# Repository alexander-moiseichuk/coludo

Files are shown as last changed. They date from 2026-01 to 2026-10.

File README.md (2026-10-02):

# coludo

This repository is to represent and control the rocket powered glider.
Since I do not know C/C++, it will be less complex than [HPR Rocket Flight Computer](https://github.com/SparkyVT/HPR-Rocket-Flight-Computer) this project will be written with MicroPython.
The composion of [hardware components](doc/hardware.md) is in progress with weight/power consumption restrictions in the account.

**Board revisions.** One firmware runs three of them and decides which it is on at boot, by I²C scan
([`layout.py`](src/glider/layout.py)) — no config edit when a board is rewired:

| rev | attitude module | also |
| --- | --- | --- |
| **v0.1** | sen0253 (BNO055 `0x28` + BMP280 `0x76`) | ADXL375 ±200 g on SPI |
| **v1.0** | sen0253 | ADXL375 removed; the ICP-10111, pitot and laser move to their own 100 kHz bus |
| **v1.1** | **sen0697** (BMI323 `0x69` + BMP581 `0x47` + **BMM350 `0x15`**) | first board with a magnetometer; the board fuses attitude itself |

The v1.1 change is measured in [TMS-7-board_v1.1_sen0697](doc/sims/TMS-7-board_v1.1_sen0697/):
across 60 board flights the two revisions fly the **same aircraft** — landing accuracy, fin activity
and in-flight health are all within run-to-run noise. What separates them is redundancy, not
performance: v1.1 gains a magnetometer and a second gyro source and gives up its second attitude
source. The magnetometer's value looked clear over 12 paired flights and did not survive 24.

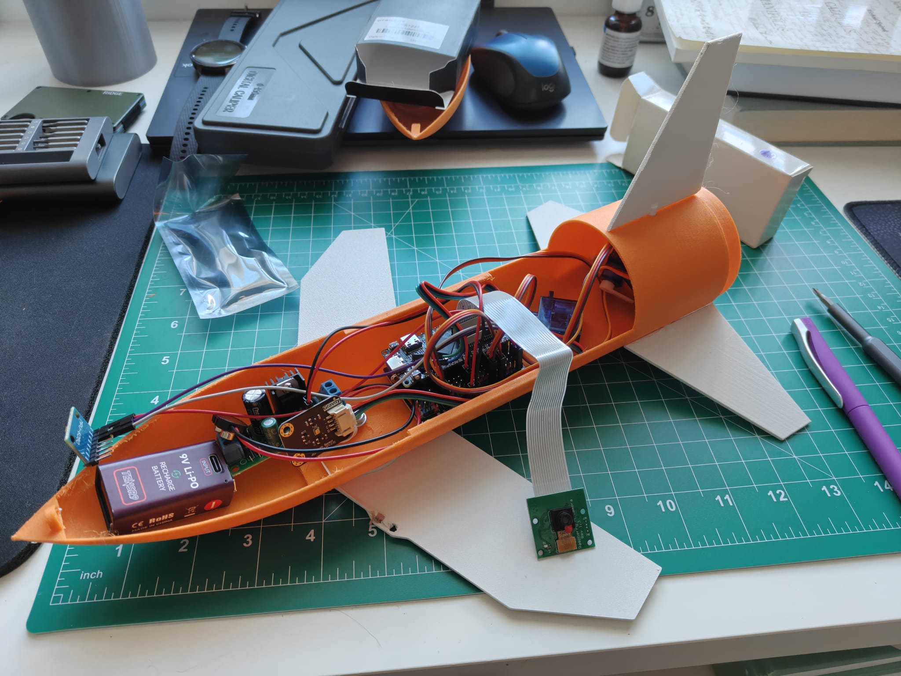
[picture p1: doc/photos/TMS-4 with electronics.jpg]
found in here
The old glider version TMS-4 can be 

The glider version TMS-7 avaliable there

## Where things live

**Specifications — [`doc/specs/`](doc/specs/)**
- [Architecture overview](doc/specs/coludo.md) — the **main description**: flight lifecycle (Setting → Boosting → Gliding → Landing), flight controller, sensors, telemetry and logging. Authoritative for flight behaviour.
- [Board configuration](doc/specs/board-config.md) — the controller's config schema, the three config layers, and the save/reboot activation lifecycle.
- [Control Center ↔ board protocol](doc/specs/cc-protocol.md) — the wire protocol between the ground station and the boards, plus the browser bridge.

**Documentation — [`doc/`](doc/)**
- [Hardware](doc/hardware.md) — parts list, weights, power budget, and candidate build configurations.
- [Data sources](doc/datasources.md) — every measured quantity with its primary source, backups and rates, per board revision, and which channels lose redundancy where.
- [WaveShare ESP32-P4-WIFI6 pin map](doc/waveshare_esp32p4_pins.md) — reserved vs free GPIOs and the recommended `board.config` pin assignment.
- [Tasks & plans](doc/plan.md) — required hardware checklist and the phased development roadmap.
- [Development & testing guide](doc/skills.md) — tooling (`ampy`/`mpremote`/`rshell`, `mpy-cross`), source layout, the `panda` test network, and the testing rules.
- [Flight simulations](doc/sims/) — closed-loop host + on-board HITL flights (noise/wind/corner sweeps) with interactive reports.
- [Benchmarks](doc/benches/) — board performance logs (BeagleBone, RPi4, StarFive).
- [Photos](doc/photos/) — build and electronics photos.
- [Videos](doc/videos/) — flight footage (e.g. the TMS-6 campaign).

**Models — [`models/`](models/)** — 3D-printable STL parts for the booster and glider prototypes (TMS-1 … TMS-7).

**Source — [`src/`](src/)**
- [`src/glider/`](src/glider/) — Main Controller flight firmware (MicroPython), with tests in `src/glider/test/`. *(implemented)*
- [`src/control/`](src/control/) — Control Center ground station (Python) + browser dashboard. *(implemented)*
- [`src/camera/`](src/camera/) — Recorder module (Luckfox Pico): 2304×1296 video + UART telemetry/log sink. *(implemented)*
- [`src/logger/`](src/logger/) — standalone nose logger (ESP32-C6 + SEN0697 + 120 mAh LiPo): a self-contained
  payload that records boost acceleration and apogee altitude for a flight the main controller is not on. *(implemented)*

**Tools — [`tools/`](tools/)** — various tools which helps in development and setup.

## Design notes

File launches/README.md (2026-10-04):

# Launches

One folder per launch day, `YYYYMMDD`, holding the flight manifest and **the board configs as they
flew**.

Configs live here rather than in a shared `configs/` because a profile is only meaningful beside the
airframe it was written for: the masses, the motor, the fin setting and the electronics fitted all
change from launch to launch, and a config that outlives them is a config nobody can trust. Regenerate
into a launch with `python3 tools/make_telemetry_config.py --launch <YYYYMMDD>` (default: the newest).
It writes the v0.1 profiles only (7C, 7D, 7D control) — keyless `layout` (declared v0.1) and the
VL53L4CX as their one enabled laser; 7E/7F are hand-kept. **Every board enables exactly one laser
entry**: an unfitted one fails `verify` and `arm`.

| launch | status |
|---|---|
| [20261003](20261003/README.md) | **flown** — [TMS-7](20261003/TMS-7/README.md) booster test: success, full flight logged; TMS-7F not assembled in time |
| ~~20260905~~ | **cancelled — weather** |

Motor masses used throughout, both measured (`doc/hardware.md`): **F15-4 98.8 g**, **E16 ~82.5 g**
loaded. Airframe masses in each manifest are **without** the motor; the totals add it.

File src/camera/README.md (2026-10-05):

# camera recoding support

It seems Luckfox Pico Mini and sc3336 can support out of box decent 2304x1296 30 FPS experience for small weight:
- board + 64 GB card
- camera
- power boost
- battery (3.7 1 cell LiPo) + 5V booster
- all together weight 30 gramms

The 32GB card or less will be sufficient but on launch pad missie may stay 15 minutes or more, so avoid losing
launch experience it must recorded in format which allows to survice for all possible frames. In top resolution
only mpeg works fine as VI channel has enought memory. The load about 30% and temperature hits acceptable 55-60C
without any passive cooling. Videos writing into /userdata/videos (see opt/camera/camerad.conf), so this area nice
to have 10+ GB as 15 mins default video consumes ~3.5GB

See sc3336.txt for possible formats but for fast implementation the existing framework is used from /oem/usr/bin:
- rkaiq_3A_server supports proper channel setup (not green, not dark)
- simple_vi_bind_venc is a nice tool to write in mjpeg (save until last frame) for ~15 mins clips (~3.5GB) with 30 FPS

You can choose (see opt/camera/camerad.conf) h264 or h265 but you have to reduce resoltution or increase CMA size in kernel
over default 24MB. Now for 64MB board 15 MB stil available and not much space to play around, so mjpeg is simply fits out of box.

# installation

push files to device, e.g.

	$ adb push opt/* /opt/

link in startup scripts e.g. 
```
	# adb shell
	# ln -s /opt/camera/camerad.sh /etc/init.d/S99camerad
	# ln -s /opt/hwclock/hwclockd.sh /etc/init.d/S20hwclockd      <--- this one optional
	# chmod -x $(which rkipc)                                     <--- it consumes a lot of cycles unnecessary
        # update date to current if you need
        # sync
        # poweroff
```

if started from USB-power supply (not PC+rndis) it will start writing files /userdata/videos/000-2304x1296.mjpeg etc.
to indicate it during boot LED does ~5s ON period and then start actively blinking following mmc1 activity,
otherwise turned off.

in case of PC script should not start allowing download videos in easy way and LED is OFF.

# recorded

The SPI + GIL seems potentially can do 80-100 ms freeze of Micropython, so to solve issue with storing telemetry and logs the recorded is required.
It works fine for 921600 bod using single wire to deliver information throgh UART to Luckfox board which needs to be configured using luckfox-config
to enable /dev/ttyS3 or /dev/ttyS4. Installation is easy - just required RX pin to be connected from TX pin of microcontoller and enabled duing boot
```
	# adb shell
	# ln -s /opt/recorded/recorded.sh /etc/init.d/S99recorded
        # sync
        # poweroff
```
Expected format is simple:
	contents line\n
or
	@target_file@contents line\n

In first case all unknown lines will be added into predefined in config file (`/userdata/recordings/recorder.log`), in second case line will be added into
`/userdata/recordings/target_file`. So, practically any logging and CSV telemetry can be stored this way.

The daemon stays exactly this simple. The board wraps every payload in an integrity check,
`{crc32};<payload>;<~crc32 ^ uptime>`, which the daemon stores verbatim and the host tools verify. It
names each boot's files by an NVS boot id, `000123_<stream>.csv`, and lists every boot and each clock
set in a shared `session.csv`. See [`doc/specs/recorder-wire.md`](../../doc/specs/recorder-wire.md).

Run the camera **off** while recording telemetry. In a closed airframe the module overheats within
~10 min (the video distorts), and video plus logging is more than it handles. `/userdata` is remounted
`commit=1` by `opt/recorder/recorderd.sh`.

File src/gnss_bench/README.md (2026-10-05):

# GNSS bench checker

[`main.py`](main.py) checks two GNSS modules in the field. They get **our flight init** plus slow diagnostics,
and the checker records what they do. It runs on an **ESP32-C6 SuperMini** with **MicroPython ≥ 1.29**. It is
not flight firmware: `tools/deploy.sh` never touches it. The first result is
[doc/benches/gnss-20261004](../../doc/benches/gnss-20261004/README.md).

## Wiring

| module | module TX → C6 | module RX ← C6 | UART | baud |
|---|---|---|---|---|
| ATGM336H | GPIO4 | GPIO5 | `UART(2)`, the C6's LP UART (fixed pins) | 9600 |
| NEO-6M | GPIO7 | GPIO6 | `UART(1)` | 9600 |

Power the C6 and both modules together. A module that powers up with the C6 gets up to 5 s to start talking
before it is configured anyway.

* **LED:** the SuperMini's RGB LED (WS2812, GPIO8). Solid **green** while it works; solid **red** once a save
  failed.
* **No button.** The SuperMini's BOOT button never registered on GPIO9 on this unit, so the checker needs
  none.

## A session per power-on

Every power-on starts session N, numbered on from the highest `336.N` on flash. Each module gets the flight
init once it talks, as `drivers/atgm336h.py` (hz 10) and `drivers/neo6mv2.py` (hz 5) send it. Then come the
diagnostics: GSV, GSA and the ATGM's antenna text every ~10 s, which leave the RMC/GGA rates as they are.
After that:

* every 10 s, a `status` line per module: RMC valid, GSA mode, GGA quality, satellites used and HDOP,
  satellites in view, the best four C/N0, the antenna text, UTC and the position;
* at a module's first 3D fix, a `fix3d` record with the last 100 NMEA lines;
* every 30 s, the moment files are rewritten with each module's last 100 lines, both at one instant, so
  pulling the battery loses at most the last 30 s.

## Files

| file | what |
|---|---|
| `336.N` / `neo6.N` | the ATGM / NEO in session N: `start`, `talking` (or `silent`), the `tx` commands sent, the first 10 NMEA lines, the `status` lines, the `fix3d` record |
| `336.N.x` / `neo6.N.x` | the last moment: `moment`, the situation, the last 100 lines |

A saved NMEA line is `<uptime ms>;<line verbatim>`. [`main.py`](main.py)'s header has the full record format.
The fixed status lines, the `fix3d` records and the moment files hold **the position at metre precision**.

## Install, read out, report

Connect the C6 **directly to the PC, never through a USB hub**: the hub corrupts mpremote transfers.

```
mpremote connect /dev/ttyACM0 cp src/gnss_bench/main.py :main.py          # install
mpremote connect /dev/ttyACM0 ls                                           # which sessions are there
mpremote connect /dev/ttyACM0 cp :336.5 :336.5.x :neo6.5 :neo6.5.x <dir>/  # read out (every N)
```

The read-out power-on starts a session too: the newest one, with almost no status lines. mpremote's Ctrl-C
ends it. To start numbering from 1 again, remove the old session files.

```
python3 tools/gnss_bench_report.py <dir> --label 1=none 5=small ... [-o summary.csv]
```

The report gives one row per session and module: the run, the 3D-fix time, when the RMC turned valid
(between two readings: the status lines and the `fix3d` record's situation), valid status lines, satellites
in view and used, the best C/N0 and the best top-4 mean, the antenna text, and the CEP50 and farthest fix
about the median. It never prints the position. Then it compares the two modules on the same satellites,
from one read-out of their moment files.

The session files hold the bench site's position: keep them local, out of git. To pin them in a write-up
without publishing them, print a keyed digest per file:

```
python3 tools/gnss_bench_report.py --provenance <dir>
```

Each line is `<file>;<HMAC-SHA256>`, keyed with `<dir>/.pepper`: 32 random bytes made on first use,
owner-only, never printed, and git-ignored by name. A plain hash would let anyone confirm a guessed position.

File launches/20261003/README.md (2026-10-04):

# Launch 2026-10-03 — HPRC

Rescheduled from **2026-09-05, cancelled for weather**.

Seven slots: one booster-only structural test, two glide-comparison airframes, one telemetry airframe,
one servo-equipped airframe, and two airframes on the new main boards: TMS-7E (v1.0) and TMS-7F
(v1.1), both built.

## Manifest

Airframe masses are **as assembled, without the motor**. Motor masses are the measured values from
`doc/hardware.md` — **F15-4 98.8 g**, **E16 ~82.5 g** loaded.

| airframe | glider | booster | motor | + motor | **liftoff** | glide mass |
|---|---|---|---|---|---|---|
| [TMS-7](TMS-7/README.md) | — | **129.5 g** | F15 | 98.8 g | **228.3 g** | n/a (no glider) |
| [TMS-7A](TMS-7A/README.md) | 183.0 g | 99.0 g | E16 | 82.5 g | **364.5 g** | 183.0 g |
| [TMS-7B](TMS-7B/README.md) | 184.3 g | 98.2 g | E16 | 82.5 g | **365.0 g** | 184.3 g |
| [TMS-7C](TMS-7C/README.md) | 216.5 g | 98.9 g | F15 | 98.8 g | **414.2 g** | 216.5 g |
| [TMS-7D](TMS-7D/README.md) | 287.5 g | 97.9 g | F15 | 98.8 g | **484.2 g** | 287.5 g |
| [TMS-7E](TMS-7E/README.md) | 250.0 g | 94.8 g | F15 | 98.8 g | **443.6 g** | 250.0 g |
| [TMS-7F](TMS-7F/README.md) | *not assembled in time — not flying 10-03* | — | — | — | — | — |

## What each slot answers

* **TMS-7** — does the new booster construction survive the strongest motor? Structure only, no glider,
  but carrying the 10 g nose logger so it also returns peak boost acceleration and apogee altitude.
  The F15 is deliberate: test the worst case before trusting it under an instrumented airframe.
  **Result: yes.** It flew to ~470 m (14.9 g peak, 125 m/s) and came back intact, and the logger returned
  the whole flight. These are the boundaries for every F15 airframe; see [TMS-7](TMS-7/README.md).
* **TMS-7A vs TMS-7B** — the wing comparison, flown as a matched pair on the same motor: **ASE wings
  with fins at 0°** against **carbon wings with fins at −5°**. Dual cameras, 1.3 g apart in mass, so the
  difference that shows up is the wing and the fin setting rather than the build.
* **TMS-7C** — telemetry. Fins **fixed at whatever 7A/7B selects**, so the instrumented flight uses the
  setting the comparison just validated rather than a guess.
  **Result: crashed.** Fins at 0°. The stack lost boost stability just off the rod (roll torque ∝ q,
  up to 9.3 g sideways), looped under thrust and hit the ground; the recorder kept 1.31 s. Hardware to
  be validated for December; see [TMS-7C](TMS-7C/README.md).
* **TMS-7D** — the servo airframe: three SG90s and the full power module.
  **Result: no separation, dropped.** It bent over in a ~4.5 m/s crosswind to a 32° path but stayed
  bounded. Apogee was 91–98 m at 5.4 s; the glider never separated, and the stack came down ~250 m out.
  The recorder kept 6.4 s. See [TMS-7D](TMS-7D/README.md).
* **TMS-7E** — the first airframe on main board v1.0, where the payoff is mass; see its folder.
  **Result: no separation, dropped.** The PCB broke in two, and the recorder's SD card is electrically dead
  (it heats to 60 °C+, never initialises), so there is no data.
* **TMS-7F** — the first v1.1 airframe (SEN0697: the board fuses its own attitude and carries a
  magnetometer); see its folder.

## What 10-03 measured — summary

Recorded flights: **TMS-7** (nose logger, the whole flight), **TMS-7C** (recorder, the first 1.31 s),
**TMS-7D** (recorder, the first 6.42 s). 7E's card died; 7F did not fly. Each flight was cut from its
recorder dump by `src/logger/flight.py` or `tools/recorder_flight.py` and measured with a gyro-plus-
accelerometer strapdown. Each was then checked by independent analyses and an adversarial judge,
recomputing from the data; the details are in each airframe's README. Not much data in total, but
enough to bound the dynamics and to show which sensors work in flight.

### What happened

| | outcome | why, as far as the data says |
|---|---|---|
| TMS-7 | **success**: 464–479 m, chute recovery | motor normal; the chute partly collapsed below ~150 m (descent 6.5 → 11 m/s) |
| TMS-7C | **looped and crashed** within ~2.5 s | a boost-stability departure at rod exit (0.31 s): near-neutral margin plus a built-in roll asymmetry; 9.3 g aerodynamic side load |
| TMS-7D | **no separation, dropped** ~250 m out | bent over in a crosswind but stayed bounded; low apogee (91–98 m); separation never happened before 6.42 s |
| TMS-7E | **no separation, dropped**; PCB broken | no data (SD card dead) |

### The corner parameters

The extremes these flights reached, against each sensor's range:

| quantity | measured | sensor range / note |
|---|---|---|
| boost peak (axial) | **14.9 g** (TMS-7, 228 g) · 8.25 g (7C, 414 g) · 6.2–6.7 g (7D, 484 g) | BMI323 ±16 g: **93 %**; peak g ≈ 32 N ÷ mass |
| shocks | 19 g (TMS-7 landing sequence), ~9 g (ejection) | **lower bounds**: 50 Hz filtering flattens them |
| lateral load | **9.3 g** (7C) · 3.6 g (7D) | aerodynamic normal force at an angle of attack of 20–30°+ |
| rotation | **1595 °/s** roll (7D), 775 (7C), 2000 = rail on 0.9 % of TMS-7's chute samples | LSM6DSO32 / BMI323 ±2000 °/s |
| speed | **125 m/s, Mach 0.36** (TMS-7) · 53.5 m/s (7D) · ~33 m/s (7C) | — |
| dynamic pressure | ~8.8 kPa (TMS-7) · ~1.6 kPa (7D) | pitot ceiling **0.546 kPa** (the sensor's own) |
| apogee | 464–479 m (TMS-7) · 91–98 m (7D) | — |
| F15 motor | **~32 N spike at 0.3 s**, burnout 2.53–2.68 s, **42 N·s**, ejection 5.8 s after burnout | the simulator flies 14.4 N × 3.45 s = 49.7 N·s, with a 4 s delay |
| descent | 6.1–6.9 m/s, then 9–12 m/s (TMS-7, chute degrading) | — |
| battery (7D) | 3.89–3.91 V, 0.47–0.70 A in flight; 1.55 A servo sweep on the pad; 198 mAh over 23.5 min of pad wait | INA226 |
| temperatures | MCU 40–42 °C, bay baros ~38 °C, logger die 35 °C (pad in the sun) | — |
| wind | ~4.5 m/s crosswind at 7D's launch (fitted); 9 m/s off the rod gave a 26° angle of attack | — |

### Sensor evaluation

Every sensor was evaluated from all recorded data: both recorder dumps (bench and field sessions), the
cut flights, and TMS-7's nose logger. Four independent analyses and a judge recomputed the numbers from
the data.

| device | airframe | status | decisive evidence | fix |
|---|---|---|---|---|
| **GNSS fix** (ATGM336H) | 7C, 7D | **not working** | **0 fixes in 11,334 GGA rows**, and no board in the fleet has ever had one. In the field it was powered and talking for 14.7 min (7C) and 23.6 min (7D) | see the GNSS section below |
| OOM forecast (`health`) | 7D | **not working** | leak 1 KB/s and 29,361 s to OOM, while memory actually fell at **360 KB/s**: OOM ~85 s away. The window was never reset after the 23 min pad wait | reset the window at GC-off / stage change, then soak-test |
| recorder SD card | 7E | **not working** | electrically dead; no data | replace it |
| **SDP810 pitot** | 7C, 7D | **degraded** | the part is fine (probes 25/25), but it reads **~0.51–0.59 of the inertial dynamic pressure** at low angle of attack. It **tops out at the sensor's own 546 Pa** (115 of 229 flight rows on 7D) and drops out at high angle of attack | calibrate the span with the flight tubing; flag ≥ 545 Pa invalid; add a static port |
| **BNO055** | 7C, 7D | **degraded** | the mount tilt is uncorrected (11–14° error); the accelerometer clips at 4 g (41 of 45 boost rows on 7C). It **output all zeros on a 7D bench session while its probe passed**, and its pitch sign flipped in 3 of 12 boots | apply the mount rotation; fail the probe on zeros; log CALIB_STAT; use it only in slow phases |
| ADXL375 | 7C, 7D | degraded (uncalibrated) | x offset **+0.78 / +0.75 g**; the scale is fine, and with the offset removed it matches the LSM6DSO32 to 0.5 % | six-position calibration; subtract the offset in firmware |
| recorder link | 7C, 7D | degraded | **~9–10 % of rows lost on battery** (97–100 % arrive on USB). The first row only arrives 28–31 s after boot, losing the headers. The tails are lost at power-off | per the recorder plan; add a per-row sequence counter |
| VL53L4CX laser | 7C, 7D | **untested** for its job | the part works, but the 2 cm it read on the pad was **the launch rod**: it vanished at rod exit with the stack intact. 47 % of rows are stale repeats | a 0–4 m drop test in glide configuration; set period = timing budget |
| INA226 ALERT; separation switch; servos in flight | 7D (7C) | untested | ALERT never exercised. The pin reads nested/separated correctly, but bench opens of 20–292 ms got through a 20 ms debounce. Servos are fine on bench and pad (117 of 117 steps) but never moved in flight | > 3 A pulse test; debounce ≥ 50 ms and log the level; servo jig after the crash |
| GNSS on the main board | 7E, 7F | untested | only the link is proven, and on v1.0 the module sits on 3V3 with no filter | the sky test below |
| LSM6DSO32 | 7C, 7D | **working** | pad \|a\| 0.99 / 1.01 g; gyro bias < 1 °/s; peaks 8.25 g and 1595 °/s, no rails | six-position calibration; a rate jig for 7D's x axis (~2 % scale suspicion) |
| ICP-10111, BMP280 | 7C, 7D | working (relative height) | σ 1.2 / 1.8 Pa; they agree within ±1–2 m in flight. The absolute BMP280−ICP split is 317 Pa (7C) and stepped to 113 Pa (7D) | re-zero ≤ 1 min before launch (weather moves it 0.1–0.2 m/min) |
| INA226, health | 7D (7C) | working | 3.9–4.1 V, 0.5–0.7 A; MCU 34 → 42 °C on the pad. The 10 Hz poll misses servo peaks | — |
| GNSS NMEA link | 7C, 7D | working | 25 of 25 probes ok; GGA cadence 1.0001 s; the "GGA lost" events are board stalls, not the receiver | — |
| BMI323, BMP581 (nose logger) | TMS-7 | working | 4891 of 4892 frames at exactly 20 ms; peak 14.8 g (93 % of range); the BMP581 is valid only when slow | — |

### GNSS: is a bigger antenna needed?

**Probably not as the main cause, and the logs can't settle it.**
- **The receivers were alive and configured** (10 Hz RMC, 1 Hz GGA) on two airframes, outdoors, for 14.7
  and 23.6 min, yet reported **zero satellites used** throughout.
- **That's too large a gap for a small antenna.** A healthy ATGM336H even on a small patch fixes cold in
  0.5–2 min. A bigger patch buys 2–6 dB; failing for 20+ minutes needs ~10–15 dB missing, or no signal at
  all.
- **The firmware turns off the evidence.** It disables GSV and the antenna-status message, so "no
  signal", "weak signal" and "jammed" look identical in these logs.

The likely causes, ranked:
1. **The installation:** interference shared by both airframes. The patch sits on the same carrier and rail as
   the Luckfox and camera, with WiFi on in both field sessions.
2. **No signal reaching the receiver:** an antenna mismatch, a connector, or a dead antenna.
3. **Orientation:** the patch faces up in glide, so on the rod it faced the horizon. It costs a few dB, not
   enough alone.
4. **A small antenna.** It may contribute, but not alone.

**The decisive test (~30 min, no firmware):**
1. Take a module, with its own antenna, off the airframe and onto a USB-UART at 9600 baud. After a power
   cycle it outputs GSV and `$GPTXT ANTENNA …` again.
2. Leave it 10 min under open sky with nothing else powered.
3. Read the result:
   - **Fix in < 2 min, strongest four satellites ≥ 38 dB-Hz:** the module and antenna are fine, and the
     installation is the problem. Re-add video, WiFi, the airframe and the vertical attitude one at a time.
   - **Nothing tracked, or ANTENNA OPEN/SHORT:** replace the antenna or the module.
   - **Satellites tracked but weak (< 30 dB-Hz bare):** only then a bigger, active antenna.

**Next flight:** log GSV every ~5 s (satellites in view and tracked, the best four C/N0) and the antenna
status. Record events for the first UTC time and the first fix. Make the pre-rod check require a fix, or at
least 4 satellites at ≥ 30 dB-Hz.

### Which sensor to trust for what

- **Attitude:** the LSM6DSO32 gyro, integrated from the pad's gravity vector. The BNO055 only in slow phases,
  once its mount is corrected.
- **Speed in boost and coast:** inertial (LSM6DSO32, with the ADXL375 as the high-g backup once its offset
  is removed). The two agree to 0.5 %.
- **Airspeed:** the pitot in the glide only (q < ~500 Pa, angle of attack < 15°), after its span
  calibration. Ignore it in boost and coast.
- **Height:** the ICP-10111 first, the BMP280 as backup, both re-zeroed just before launch. Trust any baro
  only when slow. There is no GNSS altitude yet, and the laser is unvalidated.
- **Data hygiene:** ~10 % of rows are missing on battery, and spliced rows remain (one ADXL row parses as
  2050 g). Always gate on range.

### Proposals for the post-launch cycle

Input to sit beside the operator's own ideas, most valuable first:

1. **Stack stability**, the root of 7C's loop and 7D's bent path.
   - Measure the CG with the motor, and swing-test it in both planes. Fly only at ≥ +1 caliber of effective
     margin at 20° angle of attack (7C was ~0.25, 7D ~0.71 nominal).
   - Bigger booster fins, a fairing over the folded wings, or nose ballast.
   - Jig the fins to 0 ± 0.25° and key the joint against roll.
   - A 2–3 m rail, or a wind limit.
2. **Separation**, which failed on 7D and 7E.
   - A board-fired release on a vertical speed ≤ 0, with the motor charge only as a backstop: no fixed
     delay fits apogee 2.9–5.1 s after burnout.
   - Proven energy at full glider mass after a real burn; motor retention rated above the ejection force.
   - Log the pin level; never engage control on an unseparated stack.
3. **GNSS:** the sky test above before buying anything, then GSV logging. If no fix can be had reliably,
   decide deliberately what guidance does without it: dead reckoning from a surveyed pad, which then puts
   the pitot and magnetometer on the critical path.
4. **The recorder:** the operator's plan (no video, ~2000 µF hold-up capacitor, a new file organization),
   accepted with a power-pull test. Add a per-row sequence counter so losses are countable.
5. **Firmware.**
   - A non-wrapping timestamp; set the clock so sessions carry the date.
   - Fix the OOM forecast.
   - Arm the apogee detector on measured burnout.
   - An "ejection kick" event.
   - Make the BNO055 probe fail on all-zero data.
   - Debounce the separation pin at ≥ 50 ms.
6. **Calibration:**
   - six-position tumbles (LSM6DSO32, ADXL375);
   - the BNO055 mount rotation and CALIB_STAT;
   - the pitot span with the flight tubing, plus a static port;
   - a gyro rate jig;
   - a 10-minute baro side-by-side against an airport QNH;
   - a laser drop test.
7. **The simulator:**
   - the measured F15 (32 N spike, 42 N·s, burnout 2.6 s, ejection 5.8 s after);
   - a 6-degree-of-freedom boost with wind, a q-proportional roll asymmetry and margin per plane;
   - replay regressions of 7C, 7D and TMS-7.
8. **Re-validating the reused hardware:** the checklists in the 7C and 7D READMEs, against the pad medians recorded there.
9. **Recovery:** inspect TMS-7's chute (it degraded below 150 m). Keep flying the nose logger as a black box.

## One thing the flight data already says about 7D's mass

[`TMS-7-preflight`](../../doc/sims/TMS-7-preflight/) flew 90 HITL flights across three load/thrust
combos last week. Two of them bracket the airframes here:

| study combo | glide mass | median miss | in zone |
|---|---|---|---|
| `f15_half` | 235 g | 37–46 m | **7/10** |
| `f15_full` | 285 g | 88–91 m | **0/10** |

**TMS-7D at 287.5 g is `f15_full` almost exactly**, and TMS-7C at 216.5 g is lighter than `f15_half`.

This does **not** affect 2026-10-03: 7D flies `tms7d.config`, which has servos fitted but **control
OFF**, so no airframe here attempts a guided landing. It matters for the flight after: when 7D does fly
under a PID, it will do so at the mass that landed 0 of 10 in the zone, and reaching the 235 g that
landed 7 of 10 means removing ~52 g. Better to know that before the airframe is finished than after.

## Firmware and calibration per airframe (2026-09-24)

Two firmware generations fly on purpose: the hardened build on the two new airframes, the long-tested
builds on the two that already proved themselves. Every capture stamps its firmware version, so the
groups stay separable in the data.

| airframe | firmware | config | still owed before flight |
|---|---|---|---|
| **TMS-7E** (v1.0) | `2026.09.23.55c494a0c659` | [`tms7e.config`](TMS-7E/tms7e.config) = the board's `board.config` | BNO055 figure-8, then **`calibrate imu_bno055`** (its profile has never reached NVS); pad pitot tare |
| **TMS-7F** (v1.1) | `2026.09.23.55c494a0c659` | [`tms7f.config`](TMS-7F/tms7f.config) = the board's `board.config` | BMM350 LEVEL full circle, then **`calibrate mag_bmm350`**; pad pitot tare. **Sealed: updates over WiFi only** (`tools/ota_push.sh TMS-7F ...`), no more USB |
| TMS-7C, TMS-7D | their long-tested builds (read `whoami`) | unchanged | as before |

**Calibrate over WiFi, assembled and on battery** -- a tethered airframe can do neither a figure-8 nor a
full circle. The commands go from the dashboard's send-command box (`calibrate`, params `imu_bno055` /
`mag_bmm350` / `airspeed_sdp810`); each is saved to NVS and restored on every boot. On 7F the
magnetometer refuses anything short of a real turn ("N of 8 sectors covered" must reach the count).

**On 7E/7F (the hardened build)** active commands answer `err unsafe` once airborne -- probe, verify's
sweep, arm, `calibrate <device>`, detect, set-config, reboot -- while `stage`, `disarm` and every read
stay open. A LANDING that never settles ends in DONE after 10 s (`land_timeout_ms`).

**On 7C/7D (the older builds) the operator is the guard:**
- they execute active commands in flight: send nothing but reads to them once launched, and no `all`
  commands while anything is airborne;
- never leave a stage forced: `stage setting`, then power-cycle before flight;
- tare the pitot with `calibrate airspeed_sdp810` (it persists) -- not `update {"zero": true}`, which
  is RAM-only on these builds; re-zero the baro with `calibrate baro_icp10111` (`update {"rezero": true}`
  errors there);
- a green `verify` is weaker for the ICP-10111 and the pitot on these builds (their probes pass on
  stale data): glance at the live values too.

## Plan — 2026-09-04

- [ ] check **TMS-7D**, upload the latest firmware; after final assembly the board is worked over **OTA**
- [ ] prepare firmware changes if any are needed
- [ ] close the `lmoiseichuk/launch_0905` branch

## Plan — next branch

- [ ] move the breadboard to **MicroPython 1.29** (1.30-pre carries nothing interesting and no fixes we need)
- [ ] possibly update `mpy-cross` alongside it
- [ ] settle **main board v0.2**:
  - merge **main + power** onto one board
  - merge **GNSS** in, cutting its power lines and UART run
  - a **separate I²C cluster for SDP810 + VL53L4CX**, everything else on the internal cluster
- [ ] rework the board layout for that
- [ ] rework the pin maps
- [ ] design the PCB and order it
- [ ] start building **TMS-7E** on the new main board
- [ ] disable the devices the new layout drops, in config

## After the October launch

- analysis session on the flight data
- possibly a **Rust migration**, staying on the same ESP32-P4 so the hardware is reused
- further out, a **C6 board** — only if its memory and FPU-emulation speed prove sufficient

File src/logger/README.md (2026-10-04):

# TMS-7 nose logger — ESP32-C6 + SEN0697

A standalone flight recorder for **TMS-7**, the booster-only vertical test (119.5 g airframe +
98.8 g F15 = **218.3 g liftoff**). TMS-7 carries no electronics and returns no data; this payload
makes the flight yield **peak boost acceleration** and **apogee altitude** for the cost of a few grams
in the nose.

It talks to nothing. No radio in flight, no link to the main board — a sandwich of
**ESP32-C6 SuperMini + LiPo + SEN0697**, recording from power-up to power-off and saving to flash as it
goes. USB is the development and read-out path; the status LED is the liveness check.

## The part

**SEN0697** (DFRobot Fermion, *Gravity 3126*) carries three Bosch dice on one board:

| chip | channels | range | max ODR |
|---|---|---|---|
| **BMI323** | accel x/y/z, gyro x/y/z, temperature | **±16 g**, ±2000 °/s | 6.4 kHz |
| **BMM350** | mag x/y/z | ~±2000 µT | 400 Hz |
| **BMP581** | pressure, temperature | 30–125 kPa | 240 Hz |

**The BMM350 is not wired into this mission.** A magnetometer on a vertical missile reports roll
orientation at best, and adopting it means owning hard- and soft-iron calibration next to a booster —
the exact cost that made `doc/hardware.md` reject this family for the glider's attitude role. Skipping
it saves a driver and buys nothing away.

### The one number to watch

Expected peak specific force is `25 N / (0.225 kg × 9.81) ≈ **11.3 g**`, against the BMI323's ±16 g
ceiling — **1.4× margin**, with no measured ignition transient anywhere in this project to bound the
spike. If it rails you still learn *"peak exceeded 16 g"*, which answers "did the booster survive"
but not "by how much". If the exact peak is the point, add an **ADXL375** (±200 g, already owned,
driver already written) beside it.

## Mechanical

PCB is **24 × 19 mm**, mounting holes **19 mm apart, 2 mm diameter**. That is within a millimetre or two
of a C6 SuperMini's footprint, so the sandwich stacks squarely — board, cell, board — rather than
needing an offset. Plan the stack height around the LiPo, which will be the thickest layer.

## Wiring

The SEN0697 breaks out two sides. Either works; they differ only in whether you take the interrupts.

**Verified against the ESP32-C6 datasheet (ch. 3 Boot Configurations) and ESP-IDF, 2026-09-15:**

| pin | status | why |
|---|---|---|
| **GPIO12, GPIO13** | **do not use** | native USB D−/D+. ESP-IDF: *"GPIO12 and GPIO13 are used by USB-JTAG by default. If they are reconfigured to operate as normal GPIOs, USB-JTAG functionality will be disabled."* This is the dev cable, the console and the flash read-out path. |
| **GPIO9** | **do not use** | the only pin that actually gates boot. Held LOW at reset the chip enters the ROM serial bootloader instead of running flash. It is the BOOT button, and it has an internal pull-up. |
| **GPIO8** | avoid, but **not** for the usual reason | Table 3-3 says SPI boot is `GPIO8 = any value, GPIO9 = 1` — GPIO8 is *ignored* in normal boot, so a sensor INT idling low here does **not** stop the board booting. What it does cost: BOOT pulls GPIO9 low, and `GPIO8 = 0` + `GPIO9 = 0` is documented as *"invalid and will trigger unexpected behavior"* — so you permanently lose the button route into the bootloader. On a soldered payload in a nose cone that is your last hardware recovery path. On the SuperMini it is also the **WS2812 RGB LED** data line. |
| **GPIO15** | free at chip level, **but it is the status LED** | appears only in Table 3-7 (JTAG signal source) and is *"Ignored"* with factory eFuses. Harmless electrically — but on the C6 SuperMini it drives the plain status LED, which is the liveness indicator this payload wants. |
| **GPIO10, GPIO11** | **not present** | ESP-IDF: on SiP-flash variants *"the SPI0/1 pins and GPIO10 ~ GPIO11 are not led out"*. The SuperMini is an ESP32-C6FH4 with in-package flash. |
| **GPIO24–GPIO30** | **not present** | SPI flash pins; absent on the SiP package. |
| **GPIO16, GPIO17** | avoid | default UART0 TX/RX. |

Usable set on this package: **GPIO0–GPIO9 and GPIO12–GPIO23**, minus the rows above. GPIO14 *does* exist
here — it is led out only on the SiP-flash variants, which is what a SuperMini is.

### What to solder — five wires, all on the left header

Direct to the ESP32-C6 pads, skipping the Fermion breakout, which is the compact build.

| SEN0697 | → ESP32-C6 | why this pin |
|---|---|---|
| 3V3 | **3V3** | board is 3.3 V, draws single-digit mA |
| GND | **GND** | |
| SCL | **GPIO20** | clean, adjacent |
| SDA | **GPIO19** | clean, adjacent |
| INT1 | **GPIO18** | BMI323 FIFO watermark — the only interrupt this mission needs |

**INT2, INT3 and INT4 are deliberately not wired.** INT2 is the BMI323's second channel, INT3 belongs
to the unused magnetometer, INT4 to a barometer that polls comfortably at ≤240 Hz. Leaving them off is
not a compromise for compactness — it is what keeps **GPIO8, GPIO9 and GPIO15 free**, which buys back
three things worth more than the interrupts: the BOOT-button recovery path, the plain status LED, and
the WS2812. Two independent indicators means the armed / recording / saved states can be signalled in
both blink pattern *and* colour, readable from outside the airframe without a USB cable.

### The FIFO is polled, and INT1 is spare

Both sensors' FIFOs are drained every 10 ms, so the sample rate is set by the sensor rather than by how
fast MicroPython can loop — this project measured a ~10 ms scheduling floor on the ESP32 asyncio port,
which alone would cap a Python-rate loop near 100 Hz and miss a boost transient.

Draining needs no interrupt: the loop reads `FIFO_FILL_LEVEL` each tick and takes whatever is queued.
**`main.py` never touches GPIO18.** The wire is still worth having — one conductor, and it leaves a
watermark interrupt available if a later build wants to sleep between drains — but nothing today depends
on it, and a harness without it behaves identically.

> Confirm your **SuperMini's** silkscreen against the GPIO numbers above before soldering — clone
> variants differ, and the C6 SuperMini is not a DFRobot board.

### Battery and arming switch

| from | to | note |
|---|---|---|
| LiPo **+** | switch pole → **`B+`** pad | switch goes in the **positive** line |
| LiPo **−** | **`B−`** pad | direct, no switch |

**Switch the positive line, never ground.** USB carries its own ground, so a switch in `B−` does not
isolate the cell while the dev cable is plugged in — you get a half-powered board and a confusing bench
session. In `B+` the behaviour is clean: switch OFF and the board runs from USB alone, switch ON and it
runs from the cell. Note the charger is downstream of the switch, so the cell only charges with the
switch ON.

**A slide switch can vibrate open under boost.** That loses the flight, and it loses it silently. Either
use a screw/twist switch (standard rocketry practice for exactly this reason), or secure the slide
switch mechanically once armed — a wrap of tape or a shrink sleeve over the actuator is enough. Whatever
you choose has to be reachable with the airframe closed, since the arming order is: switch on, confirm
the LED, *then* close up.

### Pull-ups and power

- **The wiki does not say whether I²C pull-ups are fitted.** Measure SDA→3V3 and SCL→3V3 with the board
  unpowered before assuming; if they read open, add 4.7 kΩ each. Operating voltage is **3.3 V**.
- This SuperMini variant **does** carry a charger: `B+` / `B−` solder pads on the underside plus a green
  charge-indicator LED driven by the charger IC (not by a GPIO) — on while charging, off with a battery
  connected, blinking with no battery. Wire the cell to `B+`/`B−`, never to the 3V3 rail.
- Add a **bulk capacitor (100–470 µF)** across 3V3. A brownout resets the logger: it loses what is
  still in RAM — up to one segment, ~15 s at full rate — and comes back under a new boot number. Saved
  segments survive; under boost, the lost seconds are the ones this payload exists to record.

## Expected I²C addresses

From the DFRobot wiki (https://wiki.dfrobot.com/sen0697/). Note every default is the **upper**
address of its pair — a scan that finds `0x68 / 0x14 / 0x46` means the straps are pulled the other way,
not that something is broken.

| chip | default | alternate |
|---|---|---|
| BMI323 | **`0x69`** | `0x68` |
| BMM350 | **`0x15`** | `0x14` |
| BMP581 | **`0x47`** | `0x46` |

## Development

**Connect the C6 straight to the PC, not through a hub.** On 2026-09-15 the replacement bench hub dropped
bytes in both directions: raw-REPL tools (mpremote, ampy, rshell) could not enter raw mode, file writes
did not commit, and the board's own echo came back with characters missing. Plugged in directly, the
same transfer verified by SHA-256 and survived a soft reset on the first try.

The C6's USB is native (USB Serial/JTAG), which changes two things you might otherwise assume:

- **The baud setting is ignored.** Data moves at USB speed whatever the port says; "slower" means pacing
  the writes, not a lower baud.
- **DTR/RTS are wired to reset and the BOOT strap** — that is how esptool auto-resets. A tool that drops
  DTR while RTS is still high resets the chip on connect. That also wipes whatever is in RAM, which is
  why the firmware saves to flash rather than relying on a read-out over USB.

Interactive: `rshell -p /dev/ttyACM0`, then `repl`. First run after soldering:

```
ampy -p /dev/ttyACM0 -d 2 run src/logger/scan.py      # -d 2: let the board settle after the port opens
```

**Recovery** if a bad `main.py` ever wedges USB at every boot: hold BOOT, tap RST — the ROM download
mode — and reflash MicroPython with esptool. GPIO9 is left unwired precisely so this path stays open.
**A reflash erases the filesystem, logs included** — pull any flight off first (below); it is the last
resort, never the way to stop the logger.

## Firmware — `main.py`

Runs at boot and records from power-on; it stops itself once a flight is over. Nothing is filtered: a
flight can be a start and a drop inside one save window, so every sample is kept.

**The lifecycle** — because TMS-7 on 2026-10-03 was three minutes of carrying from losing its flight to
the old ring buffer, which kept recording through 49 minutes on the ground and the walk back:

| state | how it starts | LED |
|---|---|---|
| **recording** | power-on, or BOOT in read-out mode | **3 long flashes** (1 s), then toggling every 0.5 s |
| **launched** | \|a\| over **3 g held 0.3 s**, confirmed by a **20 m climb within 5 s** — every frame is tested, decimated or not | unchanged |
| **stopped** = read-out mode | flight complete, BOOT, flash full of flights, or a read-out tool's Ctrl-C | **3 short flashes**, then **solid** |

- **Before a launch the flash is a ring**: when space runs short the oldest *unprotected* logs go, so a pad
  wait of any length costs nothing.
- **The launch is a flight**: it is appended to `flights.txt` as `boot segment`, and from the segment
  before it every log of that boot is protected — never deleted, by the ring or anything else.
- **Why the climb**: on the bench a hard hand shake held 3 g for 16 frames (24.8 g peak), one more than
  the 15 the run needs. Unconfirmed, that latches a launch on the pad, and 60 s of stillness later the
  logger would stop before the real flight. No hand climbs 20 m, and TMS-7 had climbed 20 m by 0.68 s.
- **Flight complete** = **60 s of stillness** after the launch (the climb test sees a chute descent as
  motion, so only the ground is still) or **10 min** after it, whichever first: the tail is saved and
  it stops. Replayed on TMS-7's raw records, the 3 g starts at +0.34 s, the climb confirms it at
  +0.68 s, and the stop comes 2.5 min after touchdown. Replayed on the bench shake, nothing latches.
- **Flash full of flights**: when the next segment could only go over a flight it stops; at power-on it
  does not start. Solid from the first second means *read me out*.
- **BOOT** is the manual stop, and in read-out mode the restart. Every reset waits for BOOT to be
  **released**: it is the GPIO9 strap, and a reset with it held lands the C6 in the ROM bootloader.
- **After a read-out**: `mpremote connect <port> exec "import main; main.clean()"` deletes every log and
  `flights.txt`, and nothing else.

| | |
|---|---|
| rate | **50 Hz**, both sensors sampling on their own clocks into their own FIFOs |
| drain | every 10 ms — twice per frame period, so a frame never waits |
| record | 24 bytes, raw: `uint32 ms · int16 ax ay az gx gy gz · int32 pressure · int32 temperature` |
| autosave | a new file every **750 records** (~15 s, 18 KB) |
| still | **1 Hz** after 5 s of stillness; the first frame that moves restores 50 Hz |
| BOOT | **stops** recording: saves the partial segment, 3 short flashes, then solid. In read-out mode it starts recording again |
| LED (GPIO15) | 3 long flashes at the start, then toggles every ~0.5 s while recording; solid = stopped |
| files | `bBBBBB_sSSSS.bin` — boot number (monotonic, kept in NVS) + segment; they sort chronologically |
| space | 2 MB filesystem, 1.94 MB free → **~28 minutes** at full rate, far longer with idle stretches |
| full flash | the **oldest unprotected** logs are deleted — only as many as the new segment needs, counted from their own sizes; flights, `main.py`, `boot.py` and `flights.txt` are never touched. When only flights are left it stops (solid) |

Each file opens with a 20-byte header, `<4sHHHHII`: magic `CLG3`, record size, sample period (ms), boot,
segment, record count, and the MCU clock at the save.

**Why the FIFOs matter.** Programming flash freezes the single core — measured at 647–1434 ms per 72 KB
save, and 1221–2004 ms once the flash was full and each save also had to delete a file. Through that
freeze the BMI323 keeps queueing accel + gyro (~3.4 s deep at 50 Hz) and the BMP581 keeps queueing
pressure (32 frames, 0.64 s), and the next drain collects it all. Measured after the change: **0 ms of
extra gap at every save join**, across 11 saves, one of them containing 23 g impacts.

Temperature is read live rather than through the BMP581's FIFO: putting it there halves that FIFO from
32 frames to 16, and temperature moves far too slowly to need buffering.

**Timestamps come from the sensor's clock** — frame N is `t0 + N × 20 ms`, evenly spaced by construction,
with no MCU jitter. The header's MCU clock is the cross-check: a lost frame would show as the sensor
timeline falling a further 20 ms behind, and on the bench it sat a constant ~70 ms ahead instead.

**Stillness is judged frame to frame**, never against a stored resting pose — a pose keeps reading
"moved" after the airframe is set down in a new orientation, and the logger would never settle. The
thresholds are 0.05 g of frame-to-frame change, 5 dps on any axis, or ~2 m of climb against the mark a
second ago; resting noise measures ~5 LSB and ~1 dps, well clear of them.

**What you can still lose:**

- **Up to one segment at power-off** — whatever is in RAM since the last save. Every stop (flight
  complete, BOOT, full) saves it first; only cutting the power mid-recording loses it.
- Nothing at start-up: the gyro reports `0x8000` until it has started, and `_setup()` waits for valid data
  before flushing the FIFO and beginning.
- **No longer the flight itself.** A protected flight is never deleted, and recording stops by itself
  once it is over. What a long recovery costs now is nothing: the logger is already stopped, LED solid.
- **A flight that never latched a launch** — a motor too weak to hold 3 g for 0.3 s at the logger's mass.
  Every F15 airframe here peaks at 7–15 g; check before flying anything gentler.

### Reading the logs off — the read-out procedure

The hardware watchdog (8 s) is fed only by the sampling loop, so a tool that stops that loop with Ctrl-C
used to let it fire mid-copy — and the reboot started recording, deleting the oldest segments once the
flash was full: the flight. Recording now starts at once but the watchdog is armed only **4 s after
boot**, and a Ctrl-C saves what is in RAM (only if it fits — it never deletes to make room) and stops:

1. **Power it on, plugged straight into the PC**, and run the copy, e.g.
   `rshell -p /dev/ttyACM0 cp '/pyboard/b*.bin' launches/<date>/<airframe>/logger/`.
2. If the tool connected within the 4 s window (a connect that resets the chip always does), the
   logger stops cleanly: `stopped for read-out`, **LED solid**, and the copy runs.
3. If the watchdog was already armed, the logger saves, flags read-out mode in RTC memory and resets
   itself — the tool loses the port once (it re-enumerates). **Run the same command again**: the board
   comes back in read-out mode — `READ-OUT MODE`, **LED solid**, not recording, no watchdog.
4. **A power-cycle or a BOOT press returns it to recording** — RTC memory does not survive power-off.
   A software reset does not, so read-out mode holds across as many tool connects as the copy takes.

A logger that **stopped by itself** after a flight (LED solid on recovery) is already in read-out mode:
step 1 copies straight away. Then `main.clean()` (above) before the next flight.

**Bench-checked 2026-10-03 on the C6**: two BOOT stops (each saving its segment), the read-out-mode
BOOT restart (RTC flag cleared and set again), and the shake above.

**Tests** run on the C6 itself, in read-out mode, with `main.py` installed:
`mpremote connect <port> run src/logger/test_main.py` — the launch test, the stillness test, the flash
pattern, the climb, the flight record and the room-making, positive and negative, in a scratch
directory (32 checks).

## Where the data lives

Logs belong to the **flight**, not to this directory: pull them into
`launches/<date>/<airframe>/logger/` (e.g. `launches/20261003/TMS-7/logger/`) so a capture sits beside
the airframe's mass, motor and configuration. Bench captures that prove something about the firmware go
in the commit that changes it; routine desk recordings are not worth keeping, and per-segment CSVs never are —
`decode.py` regenerates them from the `.bin` at any time. A flight keeps only the segments that hold it,
plus the one `flight.csv` that `flight.py` cuts from them (below), which is what the analysis reads.

## Reading the data — `decode.py`

```
python3 src/logger/decode.py launches/20261003/TMS-7/logger/*.bin
```

Writes a CSV beside each file, one row per sample. A file cut short (the header counts more records than
it holds) is decoded as far as it goes and says `truncated: N of M`; one that is not a logger file at all
is reported `SKIPPED` and the rest still decode.

`index, t_s, dt_ms, ax_g, ay_g, az_g, a_g, gx_dps, gy_dps, gz_dps, pressure_pa, temp_c, alt_rel_m, tick_ms`

- `0x8000` — the BMI323's "no sample yet" — becomes an **empty cell**, never −2000 dps. Before that rule
  existed, two start-up samples made a handheld shake summarise as a 2000 dps peak.
- `alt_rel_m` is height above **the boot's reference**: the first real pressure in the lowest-numbered
  segment of that boot among the files given. One reference per boot, not per file, so apogee reads
  the same across the ~15 s segments — pass every segment of the boot (the `*.bin` glob), or the
  reference moves to whichever segment comes first. Hypsometric with the **measured temperature**. The
  standard-atmosphere formula assumes 15 °C, and height per pascal scales with absolute temperature, so a
  30 °C pad reads ~5% low — about 15 m on a 300 m apogee. The BMP581 die sits beside the MCU and reads a
  few degrees warm, which is still far closer than 15 °C.

## A flight — `flight.py` and `flight_plots.py`

```
python3 src/logger/flight.py launches/20261003/TMS-7/logger/*.bin -o launches/20261003/TMS-7/flight.csv \
    --mass 0.2283 --propellant 0.060
~/.local/share/pipx/venvs/plotly/bin/python src/logger/flight_plots.py launches/20261003/TMS-7/flight.csv \
    -o launches/20261003/TMS-7/plots --mass 0.2283 --propellant 0.060
```

`flight.py` (stdlib) joins one boot's segments onto **one time axis, t = 0 at ignition** — the first
sample of the rise to a sustained 3 g, walked back to where it left 1.1 g. It keeps 10 s of pad before
and 10 s of rest after landing, and writes `flight.csv` with heights against the mean pad pressure. It
then prints the flight: rod exit, peak, burnout, top speed, ejection, apogee, descent by 10 s band,
tumble, the largest shock, touchdown and rest. With `--mass` and `--propellant` (kg) it adds the thrust
estimate: axial force × mass plus drag fitted from the coast.

**Speeds and heights up to the ejection are inertial, not baro.** On TMS-7 the nose-cone baro read
83 m high at burnout (suction at speed, ~a tenth of the dynamic pressure). So the strapdown carries
the boost and coast: gyro attitude levelled on the pad's gravity, the accelerometer integrated in that
frame. It stops at the ejection, past which the nose tumbles beyond the gyro's ±2000 °/s. The baro takes
over where the airframe is slow: apogee, descent, ground.

`flight_plots.py` draws from the same `analyse()`. It writes an SVG per figure (overview, boost, thrust,
descent, landing) for READMEs, and one interactive `flight.html`. It needs plotly plus kaleido, which
renders through Chrome: `pipx inject plotly kaleido`, then `plotly_get_chrome -y`, once.

## Bench results — 2026-09-15

| | |
|---|---|
| heap free after boot | 332 KB |
| sample rate | **50.0 Hz**, flat 20 ms from the sensor clock (the earlier polled build: 99.9 Hz, 10–11 ms) |
| accel scale | per-sample \|a\| median **1.000 g** at rest — ±16 g at 2048 LSB/g confirmed against gravity |
| pressure noise | 4 Pa spread while still (~0.3 m) |
| hand shake | peak 2.7 g, 549 dps |
| gyro bias | **≤1 dps** at rest, 29 °C |

## Carried over from the static-burn logger

`tools/c3_burn_logger.py` (ESP32-C3, static burn + separation ground test) is not the base for this code.
Of its three rules, two hold and one was overtaken:

- **Rotate files** — holds. A restart or brownout never overwrites an earlier capture.
- **Decimate while idle** — holds, and is why ten minutes on the ground costs ~14 KB rather than ~720 KB.
  That logger dropped to 1 row/s while waiting for ignition; this one keys on stillness itself, so it
  applies on the pad, under the chute and after landing without having to know which is which.
- **Never write flash while sampling** — overtaken rather than traded away. It was the right rule for a
  build that polled its sensors, and this one records from power-up precisely because a missed BOOT press
  must not cost the flight. The FIFOs removed the conflict instead of splitting the difference: the save
  still freezes the core, and no samples are lost to it.

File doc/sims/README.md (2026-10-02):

# Flight simulations

Closed-loop flight simulations of the Coludo glider — the *real* control code (`navigation` + `pid` +
`mixer` + `sequencer`) flown over the shared flight-dynamics model (`src/glider/sim_model.py`), in two
worlds that share the same physics: the host **virtual-flight** tool (CPython) and the on-board **HITL**
simulator (`tasks/hitl.py`, MicroPython). Each run emits a recorder capture rendered to interactive
plotly HTML + dependency-free SVG.

| Set | What was tested | Where it ran |
|---|---|---|
| [**TMS-7-basic**](TMS-7-basic/) | The original bank-to-turn glide on the TMS-7 airframe (F15): sensor-noise sweep (5–100 %), cross-wind sweep (0–12 m/s), and g16 spike-injection corner cases. The reference that showed the over-range → orbit fix (miss ~85 m). | **host** (`tools/virtual_flight.py`) |
| [**TMS-7-guarded_fins**](TMS-7-guarded_fins/) | The **g12 dynamic-pressure fin governor + boost control stage**, flown as a full matrix (noise 05–100, wind 00–12, corner spike/stress) **on the real ESP32-P4** for **both motors — F15-4 and E16-4**. Every trace (trajectory, fins, **real board vitals**) is device telemetry, collected via rshell-run / adb-take. | **board** (on-board HITL) |
| [**TMS-7-memory_refactoring**](TMS-7-memory_refactoring/) | The **GC-off memory leak** after the Phase-3 hot-path allocation work (fixed-point PID + telemetry/`note` trims), measured from the `mem_free` slope over BOOSTING→DONE. A full on-board HITL capture set of the post-refactoring firmware over the corrected TMS-7 v2 weight matrix (E16/F15 × full 300 g / half 150 g glider; booster ejects at separation). Calm, 5 % noise, 25 Hz. Each flight has a 3D report (trajectory + attitude + fins + **real INA226 servo power** + **GC-off leak/OOM**), an SVG, and a shared movie. Real-flight control-path leak measured ~24 KB/s → **time-to-OOM ≈ 10 min** (F01 + F05), well past the 180 s gate. | **board** (on-board HITL) |
| [**TMS-7-fixnums**](TMS-7-fixnums/) | The same weight matrix re-flown on the **fixed-point (`fixnum`) + gyro-D-term firmware** (centidegree integer PID/attitude/drivers, LSM6DSO32 rate as the PID D term, integer INA226). Behaviour is baseline-neutral (same trajectory, power, CPU); the HITL leak is flat (sim-dominated). The measured **real control-path leak is ~42 KB/s → time-to-OOM ~13 min** at 100 Hz (`pid.step` now 0 B/step; the residual is the deliberately-float airspeed `|accel|` chain), and each report adds a **gyro-rate panel**. | **board** (on-board HITL) |
| [**TMS-7-guiding_refactoring**](TMS-7-guiding_refactoring/) | The weight matrix re-flown after the **structural refactoring** (plan roadmap #1–#3): the control law extracted to `guidance.py` (per-stage law table) + `governor.py` (airspeed cap + adaptive throttle), the **mixer fused into the servo write** (`bind`/`actuate`), and `virtual_flight` driving the real law. **Trajectory parity is exact** (apogees to the metre vs fixnums) while the real control-path leak drops to **~15 KB/s settled → time-to-OOM ~36 min** at 100 Hz (PID+mix+servo slice 112 → 32 B/step). Four reports and SVGs (movie regenerable via `flight_video.py`). | **board** (on-board HITL) |
| [**TMS-7-loiter**](TMS-7-loiter/) | The fly-long glide law before/after (**host** sim, quality-2 polar): the old racetrack's 184 m phase-luck swings vs the **loiter orbit + endgame spiral** landing **17–18 m from the centre, in-zone, both motors** — with time aloft 121–148 % of the polar ceiling throughout. 3D reports + SVGs + the movie; the on-board confirmation matrix completes it. | **host** (`virtual_flight`) |
| [**TMS-7-warm_reboot**](TMS-7-warm_reboot/) | Eight cases on the **measured v3 weights** flying the **fly-long trim law** (objectives ① time aloft ② in-zone ③ midpoint) on the worst-case quality-2 polar: glides +30…46 % vs pitch-0, and **the E16 reaches the zone for the first time** (13.5 m in-zone light / 77 m full); F15-light 16.6 m in-zone; the endgame variance (F15-full 109 m) is the baselined open item of the glide-energy program. Plus on-board **warm start** (breadcrumb → five-signal gate → restore, both flights recovered; outage cost is a ballistic-sim artifact) and the **CC-less spiral-landing fallback** (field-agent zone, full flights). Eight 3D reports/SVGs + the FHD 30 FPS movie with per-flight what-is-flying titles. | **board** (on-board HITL) |
| [**TMS-7-attitude**](TMS-7-attitude/) | **Attitude REDUNDANCY** + loiter board provenance in one round (6 cases, v3 weights, quality-2). 4 nominal loiter cases confirm the tuned orbit + endgame spiral **on-device** — in-zone both motors both weights (miss 52–61 m); 2 drop cases **kill the BNO055 mid-glide** so the priority-1 complementary-filter backup (`tasks/attitude.py`, integer-CORDIC roll/pitch, yaw-rate-gated accel) flies the glide to a controlled landing (E16 **15 m in-zone**). Backup tracks truth to ~1° roll / ~0.5° pitch (`attitude_soak`). 6 reports/SVGs + the 30 FPS movie. | **board** (on-board HITL) |
| [**TMS-7-oo_landing**](TMS-7-oo_landing/) | The **`oo` two-lobe endgame** (the `guidance.Heading` enum + `auto` pattern selection, the Mission choosing `o`/`oo` from the zone aspect) flown across E16/F15 × full/half at **3 m/s wind**. A **documented negative result**: `oo` is stable (same-turn-sense lobes, no figure-8 divergence) and closer in still air, but overruns the 40 m strip + drifts on wind — **out of zone in 3 of 4** (F15-half in-zone at 62 m). The reliable in-zone endgame stays the single circle (`endgame_pattern: 'o'`). 4 reports/SVGs. | **board** (on-board HITL) |
| [**TMS-7_endgame_x3**](TMS-7_endgame_x3/) | The three endgame patterns **`o` / `ov` / `oo`** + the 3-tier `auto` selector (k<2→o, 2–6→ov, ≥6→oo) over the HPRC strip (k≈4.7), flown at **air-quality 2 (worst-case floor) and 5 (realistic)** via the `sim_model.trim_sink` / `VF_QUALITY` knob. The **converging `ov`** (leg-reversal reach ∝ altitude → collapses onto centre) now lands **in-zone at 22–27 m at q5 — closest of all three, beating `o` (60 m) and `oo` (74 m)** — but needs that sink budget: at the q2 floor it lacks the laps to converge (110 m) so `o` stays the floor-safe default. `ov` beating `oo` on the k≈4.7 strip pushed the `oo` tier out to k≥6. 3 reports + 3D overlay + plan SVG. | **host** (`virtual_flight`) |

| [**TMS-7-physics_refresh**](TMS-7-physics_refresh/) | The canonical matrix (E16/F15 × full/light, calm) re-flown after the sim gained the three things it was missing: an **airspeed drag polar** (sink ∝ the polar, min-sink at ~0.76×trim as on a real glider — calm-at-trim runs are unchanged, the *shape* was the gap), **gusts** (an OU disturbance, default 0 so earlier studies reproduce), and **fault injection** (`VF_FAULT=gnss@30`; a faulted pitot RAILS rather than going silent, the dangerous under-read). Two new results: the converging endgame **degrades gracefully under gusts** (27→39 m at 3 m/s 1-σ, still in-zone — its robustness margin was previously unknown), and an injected **pitot failure costs nothing** (27.0 m, identical to baseline) because the saturation guard falls back to the accel backbone, while losing **GNSS costs 720 m**. | **host** + **board** |
| [**TMS-7-phase5_refactor**](TMS-7-phase5_refactor/) | The canonical matrix re-flown **on the board** after the phase-5 refactor round (bus `bind()` extraction, `.mpy` deploy onto a wiped board, a CORDIC that is accurate at small magnitude, and the **simulated pitot**). Three of four cases land within **2 m** of the host quality-2 prediction and `f15_full` reproduces the previous board runs inside their own 0.5 m spread — the refactor is behaviour-neutral on the flight path. The new signature is the pitot finally being IN the loop: the governor tracks it to ~0.2 m/s (was a 14.1 m/s estimate with the real bench sensor gated out all flight), and the ±500 Pa **saturation guard is exercised on the board** for the first time. Also reconciles **TMS-7-loiter**, whose 17–18 m in-zone numbers predate the harness correction and do not survive (~100 m optimistic). Investigating the leak found the **OOM forecast was unusable** (271→155→119→None→362 s, and it arms a 200 ms mid-glide collect) and the rescue was firing on a **third redundant safety margin** — both fixed, pauses halved from 10 to 5 across the matrix with the heap never below 16 MB of ~30. | **board** (on-board HITL) |
| [**TMS-7-phase5_irq_guarding**](TMS-7-phase5_irq_guarding/) | The same matrix re-flown after `commons.Waiter` replaced `asyncio.wait_for_ms` in the interrupt-driven drivers (560 B/call → 48 B), and after `irq_runs` was added to their telemetry. Confirms the rewrite is **behaviour-neutral** — accuracy, glide span, fin travel, servo energy and rescue counts all inside run-to-run scatter — and carries a warning: the **331 → 199 KB/s leak win is invisible in HITL by construction**, because `_SIM_SENSORS` masks the exact drivers that were fixed. Run without HITL, `irq_runs` exposed the LSM6DSO32's misplaced INT1 wire as a hard **0** against the ADXL375's clean **1** — a fault that leaves the sample values looking entirely plausible — and then confirmed the operator's repair (32 samples → 920, all 1). | **board** (on-board HITL + real-driver run) |
| [**TMS-7-noise_tolerance**](TMS-7-noise_tolerance/) | Every main sensor driven to **100 % noise individually** (F15 full, quality-2, new `VF_NOISE_<CHANNEL>` knob). Refutes the hypothesis on record: attitude, gyro rate and heading at twenty times nominal move the landing by **at most 5 m**, so the control law needs no steering filter. The fragility is in the **SEQUENCER** — 100 % accel noise means the launch is **never detected** and the glider never leaves the pad, and 100 % baro noise fires apogee **2.8 s early** (separating at 168 m instead of 268 m). A missed launch costs the whole flight; 100 % attitude noise costs 5 m. | **host** (`virtual_flight`) |
| [**TMS-7-precatapult_evaluation**](TMS-7-precatapult_evaluation/) | Seven board flights on the tree about to fly the catapult ladder: the four-case matrix plus a zero-noise reference and two fault cases, after `bank_limit` 30 -> 45. **The first in-zone landings this project has recorded** -- 3 of 7, best **14 m** (`f15_light`), every case improved (`e16_full` 88.7 -> 24 m, `f15_full` 121.7 -> 82 m, calm 113 -> 52 m). The loiter orbit is flown under `bank_limit`, and at 30 deg its turn floor `R_min = v^2/(g*tan phi)` is ~40 m while `loiter_radius_m` commands 30 m -- the law asked for a circle tighter than the airframe could fly, so the heading controller saturated (`roll_sp` pinned at +/-30, `heading_err` 112-157 deg) into a limit cycle: a ~65 m orbit centred ~95 m off target, swinging 28 <-> 163 m on a ~26 s period. Two wrong diagnoses preceded it -- 'navigation failure' (the zone centre is 49.5 m from the pad against ~860 m of glide range) and 'bank authority is irrelevant' (that checked `land_bank_limit` 45, the final approach, not `bank_limit` 30, the loiter). Fault tolerance re-measured at the new bank: a 60 s GNSS blackout costs ~8 m and a dead BNO055 ~27 m, against 720 m before dead reckoning existed. | **board** (on-board HITL) |
| [**TMS-7-catapult_evaluation**](TMS-7-catapult_evaluation/) | The precatapult seven re-flown with one change: `sim_model.AIR_QUALITY` **2.0 -> 5.5**, the first **measured** polar (hand toss of TMS-7B, 8.0 m of glide from a 1.40 m release against a 2.70 m ballistic dummy -> L/D 5.7; 5.5 is the conservative midpoint). Accuracy got **worse** -- 3 in-zone -> 1, flights roughly doubled -- and that is the result: the precatapult "first in-zone landings" were the energy budget expiring at the right moment, not control. At q2 the glider reached the zone with **1-8 m** of altitude and touched down where it arrived; at q5.5 it passes within **2-4 m of centre with 27-58 m in hand**, then flies the holding pattern away and lands 53-101 m out. **The guidance cannot convert excess altitude into a landing.** Sweeping the polar shows why the patterns cannot be tuned around it: miss is orbit PHASE at altitude-zero, so `ov` spans **111 m** across q2-6.5 and `oo` 67 m, while the plain circle `o` spans **21 m** -- and `auto` picks `ov` on the HPRC strip (k~4.7), the highest-variance of the three. The [endgame_x3](TMS-7_endgame_x3/) tier boundaries were set from one polar and the ranking inverts on the current tree at q5. Also: board and host agree to ~2 s of duration and ~10 m of miss now that `AIR_QUALITY` is one constant instead of two copies. | **board** (on-board HITL) + **host** sweep |
| [**TMS-7-board_v1.0_polishing**](TMS-7-board_v1.0_polishing/) | **76 board flights** after the 2026-09-22 launch-hardening pass. **r7 — did the hardening change the aircraft?** No: against r4 (v1.0) and r5 (v1.1), re-scored with the same tool, the SAME seven `f15_half` scenarios land in the zone, the misses repeat to the metre (24.4/24.7/25.4, 84.8/85.1/83.6 m), medians 70.2/67.7/71.8 m, fin work within 1 %; leak +3 % for the two new streams (`attitude.csv`, `power_ina226.csv`), and **servo energy is back** (median 57.6 J; 26.4 J E16, 70.8 J F15 half) after every round since the v1.0 rewire lost it. **r8 — the attitude filter flying ALONE, GNSS healthy** (7F's normal mode): 0/10 in zone vs 7/10, but NOT the filter's verdict -- the sim publishes `accel` as a magnitude on one axis with no gravity direction, so the filter reads the glide pitch as level (+4 to +10 deg error in EVERY flight) and the glider dives; heading is excellent in calm air and converges on the GNSS track in wind, by design. Needs a body-frame specific force in the sim (its own study), and casts a caveat back on the SEN0697 study's r6. **r9 — mid-glide reboot through the REAL restore**: found the rig could never have worked (`warmstart` imported too late, so NO HITL flight had ever checkpointed, and a refused gate printed OK); fixed, the restore passes 3/3 and the post-restore crumb keeps its identity. **r7b — r7 with the checkpoint running**: flight unchanged, the crumb costs ~5 % of the GC-off allocation rate -- and a post-landing hazard surfaced: a glider stuck in LANDING (never reaching DONE) has no GC and no rescue, and ran from ~18 MB to 0.5 MB in ~54 s. | **board** (on-board HITL, r7-r9 + r7b) |
| [**TMS-7-board_v1.1_sen0697**](TMS-7-board_v1.1_sen0697/) | **54 board flights** after the SEN0253 gave way to the **SEN0697** (BMI323 `0x69` + BMP581 `0x47` + **BMM350 `0x15`**, a magnetometer the airframe never had). Two questions. **r5 — does the new attitude module change the aircraft?** No: against the v1.0 baseline (r4) the in-zone SET is IDENTICAL in `f15_half` -- the same seven scenarios land in the zone, the same three do not, and the three that miss miss by the same amounts (24.4 -> 24.7 m, 84.8 -> 85.1 m). Medians move 6-8 m in BOTH directions across the three combos, inside the 3.0-50.4 m run-to-run spread the v1.0 study measured on an unchanged build. **r6 — what is the magnetometer worth?** 12 matched pairs, same scenario with the mag and without, under a 30 s GNSS blackout WITH the sim attitude killed (without that second drop the priority-0 sim attitude shadows the backup where the magnetic yaw lives, and the code under test never flies -- the first attempt at this round was thrown out for exactly that). Flown FOUR times -- twice on the v1.1 board, twice more after the rewire back to v1.0 (same firmware, same simulated mag, so repeats) -- and **the first two rounds did not survive the second two**: what looked like a clear win at 12 pairs (drift median +3 m vs +84 m, mag closer in 9 of 12) settles at 24 pairs into **drift median +20 m vs +64 m, landing 112 m vs 129 m, mag closer in only 13-14 of 24** -- a coin toss per flight with a median that still favours the mag. Recorded as **probably helps, not yet demonstrated**: keep the part (it rides a module that is fitted anyway), do not plan around it. **Overall the two revisions are the SAME AIRCRAFT** -- landing 70.2 m vs 67.7 m median, fins 3256 vs 3232 moves and 11612 vs 11584 deg of travel (under 1 % apart over 30 flights), health within 3-6 % (leak 367 vs 377 KB/s, rescues 122 vs 129) -- which is also the only answer HITL can give, since it masks every real sensor. So the choice is REDUNDANCY, not performance: v1.1 trades its second `attitude` source (BNO055 p0 + board filter p1 -> filter ALONE) for a magnetometer and a second gyro. Battery is unanswerable here at all: the INA226 sees the servo rail, driven by fin activity that is identical -- sensor quiescent draw needs a bench measurement on battery. Caught before flying: `_SIM_SENSORS` did not mask the new parts, so a STATIONARY bench magnetometer would have been the only publisher of `mag` in every simulated flight. `corner_stress` is excluded throughout -- it never lands inside the 150 s cap, in r4 either. Also found here: `config_hitl` never resolved the layout, so `power_ina226` -- the one real sensor HITL does not mask -- sat on the wrong bus and **every round since the v1.0 rewire silently lost the servo-energy KPI** (`flight_kpi` omits the line rather than reporting it missing); fixed, and a verification flight records 23.4 J / 0.23 W again. | **board** (on-board HITL, r5 + 4x r6) |
| [**TMS-7-board_v1.0_validation**](TMS-7-board_v1.0_validation/) | **90 board flights + a 70 000-frame bus sweep**, after the breadboard was rewired from the v0.1 bus layout to v1.0 (four devices move bus, `i2c:1` drops to 100 kHz, ADXL375 removed). Two questions wanting OPPOSITE answers: the buses should improve, the aircraft should not change. Both did. **ICP-10111 corruption 0.50 % -> 0.000 %** (2/400 on i2c:0 at 400 kHz, then **0 in 10 000** on i2c:1 at 100 kHz, where the old rate predicts ~50 events) -- and the mechanism is the CLOCK, not isolation, since the ICP still shares its bus with the pitot and laser. All seven devices read 10 000/10 000 clean across i2c:0, i2c:1 and spi:1, measured with two detectors because five of them have no checksum: CRC parts validate themselves, the rest are read at an identity register whose value cannot legitimately change. `layout.detect()` recognised the board **4-0 in both directions** across the rewire and re-bused itself with no config edit; 21 devices up, suite 58/58. Flight is unchanged to within the endgame's own phase variance, which is the DESIRED result -- `f15_half` reproduces its band and its seven in-zone scenarios. `f15_full`'s median band is disjoint and LOWER, and the study refuses to call that an improvement: it moved because variance exploded (`wind00` spread 3.0 m -> 50.4 m), and a median that falls because its inputs became less predictable is not a better aircraft. One open item recorded rather than dismissed: `e16_full` lost its single in-zone landing in ALL THREE runs, on `wind03`, previously the tightest scenario in the whole study at 1.9 m spread. The board's payoff is **mass**, not accuracy: 30-50 g of deleted harness and shorter nose, worth ~45 m of median miss at the measured 0.9 m/gram. | **board** (on-board HITL, 3 runs) |
| [**TMS-7-preflight**](TMS-7-preflight/) | **90 board flights** -- three load/thrust combos (`e16_full` 285 g/28.5 N.s, `f15_full` 285 g/49.7 N.s, `f15_half` **235 g**/49.7 N.s) x 10 scenarios x 3 runs, after the findings-43/44 fixes. **The headline is mass, not code:** `f15_half` lands at a **37-46 m** median against 71-77 m for `e16_full` and 88-91 m for `f15_full`, and puts **7 of 10 in the zone in all three runs -- the SAME seven every time**, which is a far stronger result than a matching median. The mechanism is measured time aloft (~49 s / ~100 s / ~116 s): lower wing loading buys LOITER, which the endgame pattern can spend, where [catapult_evaluation](TMS-7-catapult_evaluation/) showed extra HEIGHT is spent flying away. Medians reproduce to **2.9-9.2 m**, but single scenarios do not: each run threw one **30-60 m excursion in a different scenario** -- `wind06` read 55.9/115.0/58.6, so r1 and r3 agree to 2.7 m and r2 is a lone orbit-PHASE excursion (predicted before r3 flew, confirmed by it), and `wind00` swung 26 m in CALM air. So a regression claim here must clear ~30 m per scenario or use the median. `corner_stress` hit the 150 s cap in **9 of 9** occurrences while no other scenario timed out once -- its 460-680 m is where the clock stopped mid-LANDING, not a touchdown, so its spread is not an accuracy number (medians are immune: it is always the largest of ten). `noise50`/`noise100` were dropped as unusable, and the data agreed on sight: same firmware an hour apart gave `noise100` 113.2 m and 49.3 m. Panel comparison over 23 quantities: **0 channel dropouts in 90 flights**, 2 physically-impossible values (bit flips in correct-width rows, caught only by the bounds check), and memory genuinely irreproducible (`rescues` 1/1/3 on one scenario). **No regression** from the audit's firmware changes; board suite 57/57 on the deployed build. | **board** (on-board HITL, 3 runs) |
| [**TMS-7-postaudit_regression**](TMS-7-postaudit_regression/) | **216 board flights** -- the 12-scenario matrix x F15-4 and E16-4, flown FOUR times, to establish how much a run varies against ITSELF before any build is judged against it. Repeatability is not one number: the wind family repeats to a **7.7 m** median spread and `noise05` to **1.7 m across four runs**, while `noise100` spans **154 m** -- same aircraft, same code, so a change is only detectable if it exceeds its family's own spread. All 11 report panels are compared as 23 quantities (552 comparisons/pairing) via `tools/hitl_compare.py`, which flags PHYSICALLY IMPOSSIBLE values separately from wide ones because a ratio cannot tell noisy from corrupt. That caught an airspeed of 1.44e12 cm/s and a heading error of 15330 deg -- both traced to spliced recorder records (a truncated row losing its newline, the next record's fields landing in its columns), measured at 20 lines in 1,004,804 across 48 flights, the same class that once produced a reported L/D of 64. Also an honest negative: sizing the recorder UART txbuf 256 -> 8192 with a chunked drain produced **no demonstrable reduction** (40 events vs a 41-49 baseline; the sample can detect a halving, not 35%), so the loss is not on the sender. At the RUN level all four agree -- duration to 3.0 %, servo energy to 5.8 %, median miss to 11.7 % -- and scenario ORDERING reproduces at Spearman **0.935-0.959** among r2/r3/r4, with `noise100` holding rank 20 of 24 in every run. But r1 correlates with the others at only 0.746 (2.7 sigma), and that could NOT be resolved from the data: the boot provenance line has no `@session_file@` prefix, so the Luckfox never routes it to a .csv and every HITL capture ever taken discarded it at the transport. Captures now carry a validated build stamp. Re-flown as r5/r6 after the findings-41 fixes, which gave a clean POSITIVE CONTROL: attitude roll range held at 0.58 deg across r2/r3/r4 and stepped to **57.52 deg** at r5, a 98.6x jump exactly where the units fix landed -- before it, every board HITL capture drew a glider banking +/-29 deg as a flat line. Flight behaviour unchanged (duration spread 0.8 %). The energy metric then fell 57 -> 36 J and that was NOT code: identical fin travel with monotonically falling rail current exposed a **dead servo_eleron_right** (25 mW vs its partner's 2925), so servo energy is a bench measurement, not a flight metric. r7 replaced the part and closed the loop: rail current and energy recover (836/823 -> 1052 mA, 36 -> 54 J) while miss and duration never moved across any run -- HITL flies from COMMANDED fin angles, so a dead actuator changes what the rail sees and nothing about what the aircraft does. r5/r6 flight data is valid; only their energy figures are void. No regression from the audit's firmware changes, now bounded rather than hedged. r8/r9 then re-flew the findings-42 fixes -- r9 mattered because it changed the STAGE MACHINE, switching all four detectors (launch, apogee, landing, stationary) to source-gated reads: a gate that is too strict does not raise, the stage simply never advances, and no unit test can see that. **24 of 24 r9 flights reached boosting and gliding**, with miss agreeing to 3.7 % and duration to 1.3 % across r7/r8/r9 -- the tightest three-run agreement here. | **board** (on-board HITL, 9 runs) |

Each subfolder's `README.md` has the per-scenario metric tables (miss / in-zone / max-from-pad /
duration), the findings, and the regenerate commands.

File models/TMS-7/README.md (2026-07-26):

# 3D model data after printing TMS-7

## Geometry of Coludo 

Measured on printed model without holder.

|Component|Measured Size in mm|
| --- | --- |
|Booster Body Length  |  294  | 
|Glider Body Length |  398  |
|Full length of Coludo|  710  |
|Wing Span Extended |  605  |
|Wing Span Closed Near Holder  |  76  |
|Wing Span Closed Near Locker  |  108  |
|Fin Span |  190.5  |

These numbers are coming from the printed TMS-7 models.
Coludo consists of an upper part that is a glider and the lower part that is a booster. 
Until separation wings are in a folded state. Near the holder of the glider's side is less
 then the wing span than the locker on the Booster side. Meaning the wings are closed 
 but they are still slightly spread out. 

## Booster

Booster is the lower part of Coludo which may have E16 or F15 solid rocket propellant engines. 

|Component|Count|Weight [g]|
| --- | --- | ---- |
|Bottom  |  1  |  56.2  |
|Top|  1  |  28.1  |
|Cap|  1  |  6.5  |
|Parachute and cord|  1  | 5  |
|E16-4 Engine |  1  | 82.5 |
|F15-4 Engine |  1  | 98.9 |
| ------------------- | --- | ---- |
|Full Booster Without Engine|  1  |102.0 |
|Full Booster With E16-4 Engine|  1  | 184.5 |
|Full Booster With F15-4 Engine|  1  | 200.9 |

## Glider

The Glider is seated on top of the Booster and its wings are in a folded state until separation. 

|Component|Count|Weight [g]|
| --- | --- | ---- |
|Front Lower Body |  1  |  9.2 |
|Front Upper Body |  1  | 12.0 |
|Back Lower Body |  1  | 29.1 |
|Fin |  3  | 3.7  |
|Left Wing |  1  | 26.7 |
|Right Wing |  1  | 26.7 |
|Stopper |  1  | 0.5  |
| ------------------- | --- | ---- |
|Glider Construction with all of the above | 1 | 115.3 |

## Glider Electronics

The Glider's electronics accounted according to [board_layout.md](doc/board_layout.md) and each board includes the 2.5 gram electric pad as per Carrier-Board split.

|Component|Count|Weight [g]|
| --- | --- | ---- |
|Forward I2C Sensor  |  1  |  15.4|
|IMU (SPI) + Main Board|  1  | 20.3 |
|Aft Power/INA Carrier|  1  | 14.0 |
|GNSS + Recorder + Camera|  1  | 20.0  |
|Separation Switch |  1  | 2.0 |
|Servo Motor |  3  | 11 .0|
|Cable |  4  | 7.8  |
|Battery |  1  | 19.0  |
| ------------------- | --- | ---- |
|Glider Electronics  | 1 | 154.9 |

## Coludo assembled

Weight with whole assembly having around 155 grams of electronics on board. 

|Component|Weight [g]|
| --- | ---- |
|Coludo as Glider and Booster without engine |  372.3 |
|Coludo + E16-4 engine |  454.8 |
|Coludo + F15-4 engine |  471.2 |

## Derived geometry (from STL analysis)

Wing and fin planform areas measured from the v4 STL meshes (see `glider/` and `booster/`). The
STL coordinates are in mm; planform = one-side projected area. Wing geometry is unchanged from v3;
fin and body thickness increased.

| Component | Span [mm] | Root chord [mm] | Tip chord [mm] | Planform [cm²] | STL volume [cm³] | Notes |
|---|---|---|---|---|---|---|
| Left Wing | 299 (semi) | 79 | 20 | 148 | 24.2 | trapezoidal, nearly unswept |
| Right Wing | 299 (semi) | 79 | 20 | 148 | 24.2 | mirror of left |
| **Total wing** | **598** | — | — | **296** | **48.4** | **AR 12.1** |
| Fin (×3) | 79.5 | 69 | ~24 | 35.6 | 10.9 each | thickness increased vs v3 |
| **Total fins (3)** | — | — | — | **107** | **32.8** | all 35.6 cm² each |

Wing thickness is 2.0 mm (from Y-span of STL bbox), giving a thickness/chord ratio of ~2.5 %
at root and ~10 % at tip. Aspect ratio (AR) = b²/S = 0.598² / 0.0296 = 12.1 — high,
favourable for induced-drag efficiency. The fins are trapezoidal with 79.5 mm span and
69 mm root chord, tapering to ~24 mm at the tip; their combined area is ~36 % of the wing,
providing generous directional and pitch authority. Fin thickness increased from ~2 mm (v3)
to ~3 mm (v4), adding stiffness without changing planform.

### Body volume changes (v3 → v4)

The v4 models increase glider body wall thickness for structural strength, redesign the
booster for heat resistance, and add new parts (Electric Pad, Retainer, Retention Pin).
STL enclosed volumes:

| Component | v3 (cm³) | v4 (cm³) | v4 measured (g) | Change |
|---|---|---|---|---|
| Glider Back Lower Body | 66.2 | 79.1 | 29.1 | +19 % vol |
| Glider Front Lower Body | 27.4 | 30.4 | 9.2 | +11 % vol |
| Glider Front Upper Body | 46.5 | 46.1 | 12.0 | −1 % vol |
| **Glider body total** | **140.1** | **155.6** | **50.3** | **+11 % vol** |
| Booster Bottom (was Body Tube) | 137.1 | 56.8 | 56.2 | split redesigned |
| Booster Top (was Holder) | 20.0 | 82.8 | 28.1 | split redesigned |
| Booster Cap | 7.4 | 7.2 | 6.5 | −3 % |
| **Booster total** | **164.5** | **146.8** | **90.8** | **−11 % vol** |

Despite the +11 % glider body volume increase, the printed glider structure weight
stayed at 115.3 g (same as v3) — the thicker walls were offset by reduced infill
and optimised slicer settings. The fins are lighter (3.7 g each vs 6.4 g) due to
a simplified mesh (96 vs 408 triangles) and lower infill. The booster weight
increased from 82.6 g (v3, parts only) to 102.0 g (v4, full assembly with hardware)
— the redesigned parts include engine retention and assembly hardware that were
previously unaccounted.

New parts added in v4: Electric Pad (STL volume 5.1 cm³, serves as the 2.5 g pad per
Carrier-Board split), Retainer, and Retention Pin. Their weights are included in the
electronics and assembly totals above.

## Performance estimates

Basic-fidelity estimates using the measured v4 masses (glider structure 115.3 g,
booster 102.0 g, electronics 154.9 g), motor data from Estes specifications
(E16-4: 28 N·s / 1.8 s burn / 33 N peak; F15-4: 50 N·s / 3.5 s burn / 25 N peak),
and aerodynamic parameters derived from the STL geometry. The "100g electronics"
and "150g electronics" columns are scenarios including ~35 g of ancillary mass
(battery, wiring, adhesives). Assumes: sea-level ρ = 1.225 kg/m³; Cd = 0.6 for
the boost configuration (frontal area ~17 cm² = glider body ~46 mm effective
diameter); no wind; vertical launch.

### Boost phase

| Parameter | E16-4 | F15-4 |
|---|---|---|
| Liftoff mass (v4 measured) | 455 g | 471 g |
| Liftoff mass (100 g elec scenario) | 451 g | 468 g |
| Liftoff mass (150 g elec scenario) | 501 g | 518 g |
| Peak thrust / weight ratio | 33 N / 4.46 N = 7.4 | 25 N / 4.62 N = 5.4 |
| Peak specific force (accelerometer reads) | **~7.4 g** | **~5.4 g** |
| Ideal Δv (impulse / avg mass) | 65.9 m/s | 115.2 m/s |
| Gravity loss (g × t_burn) | −17.7 m/s | −34.3 m/s |
| Drag loss (approx) | −4 m/s | −20 m/s |
| **Burnout speed (vertical)** | **~44 m/s (158 km/h)** | **~61 m/s (220 km/h)** |
| Coast to apogee | ~98 m | ~188 m |
| **Apogee** | **~140 m** | **~290 m** |
| Time to apogee | ~7 s | ~11 s |

For the F15, the longer 3.5 s burn means drag accumulates more, narrowing the gap to the
E16 vs. the ideal-impulse-only prediction. The E16's higher peak thrust (33 N vs 25 N)
gives it better early acceleration despite lower total impulse.

### Glide phase (post-separation)

| Parameter | 100g electronics | 150g electronics |
|---|---|---|
| Glider mass (structure + elec) | 250 g | 300 g |
| Wing loading (W/S) | 8.3 kg/m² | 9.9 kg/m² |
| Stall speed (CL_max 0.7) | ~14 m/s (~50 km/h) | ~15 m/s (~54 km/h) |
| Best glide speed (CL 0.4) | ~17 m/s (~61 km/h) | ~19 m/s (~68 km/h) |
| Estimated L/D (flat plate, low Re) | **5–10** | 5–10 |
| Sink rate at best glide | 1.7–3.4 m/s | 1.9–3.8 m/s |

### Mission summary (100g electronics, mid L/D ≈ 6)

| | E16-4 | F15-4 |
|---|---|---|
| Apogee | ~140 m | ~290 m |
| Glide range (L/D 6) | ~840 m | ~1740 m |
| Glide time | ~50 s | ~100 s |
| Total flight time | ~55 s | ~110 s |

### Key differences from earlier estimates

The original coludo.md assumed a much smaller wing (124 cm² total vs 296 cm² now) and
correspondingly higher wing loading (19 vs 8.3 kg/m²). The larger wings are the single
biggest improvement:

- **Stall speed dropped from ~19 m/s to ~14 m/s** — the glider is now controllable
  instead of always flying at the edge of stall.
- **Wing loading halved** — a gentler glide, lower sink rate, and more margin for turns.
- **Boost apogee is lower** than originally estimated (~140 vs 180 m for E16, ~290 vs
  360 m for F15) because the actual printed glider structure (115.3 g) with full
  electronics (154.9 g) gives a stack ~372 g — heavier than the earlier ~270 g
  airframe-only estimate. Despite similar glider and booster weights to v3, the
  electronics now accounted (board_layout.md) add ~155 g to the total stack.

The net effect is a vehicle that climbs less high but glides much better once separated
— trading peak altitude for flyability, which is the right trade for proving active
control.

## Speed envelope

### Speeds at a glance

All values for the 250 g glider (100 g electronics scenario) unless noted.
CdA = 0.00173 m².

| Speed | Value | Notes |
|---|---|---|
| Stall speed (Vs) | **~14 m/s** (~50 km/h) | CL_max 0.7, at 8.3 kg/m² wing loading |
| Best L/D speed | **~17 m/s** (~61 km/h) | CL 0.4, mid-range of L/D polar |
| Manoeuvring speed (Va) | **~31 m/s** (~112 km/h) | Full deflection × limit load (5 g); above this, full throw overstresses the wing |
| Maximum level speed | **~30–37 m/s** (108–133 km/h) | At minimum usable CL ≈ 0.1–0.2 in a glide |
| Maximum dive speed (E16 launch) | **~37 m/s** (133 km/h) | Achievable from 140 m apogee in a steep dive |
| Maximum dive speed (F15 launch) | **~45 m/s** (162 km/h) | Achievable from 290 m apogee |
| Terminal velocity (Vt, vertical) | **~48 m/s** (173 km/h) | Limit of drag = weight; glider cannot exceed this regardless of starting height |
| Never-exceed speed (Vne) | **~47 m/s** (~169 km/h) | 1.5× Va; above this, a gust or full pull-up may exceed 5 g |
| Fin full-authority ceiling | ≤16 m/s | ±45° available |
| Fin reduced-authority floor | ≥50 m/s | ±5° only; see schedule in coludo.md |

### How each limit is derived

**Stall speed** — from the lift equation:

```
Vs = sqrt(2 × W / (ρ × S × CL_max))
   = sqrt(2 × 0.250 × 9.81 / (1.225 × 0.0296 × 0.7))
   = 13.8 m/s  → ~14 m/s
```

CL_max = 0.7 is conservative for a thin flat-plate wing at Re ≈ 50 000–100 000.
A smoother carbon surface may raise it to 0.8–0.9, lowering Vs to ~12–13 m/s.

**Terminal velocity** — drag = weight in a vertical dive. Total effective drag area
CdA ≈ 0.00173 m² is the sum of fuselage (Cd 0.4 × 0.0023 m²), wing profile (CD0 0.02 ×
0.0296 m²), and fin profile (CD0 0.02 × 0.0107 m²), all referenced to 1.225 kg/m³:

```
Vt = sqrt(2 × W / (ρ × CdA))
   = sqrt(2 × 0.250 × 9.81 / (1.225 × 0.00173))
   = 48.2 m/s  → ~48 m/s
```

For the heavier 300 g glider: Vt ≈ 53 m/s (190 km/h).

**Manoeuvring speed Va** — the speed at which the wing reaches CL_max = 0.7 at the
limit load factor n_lim = 5 g (typical for small RC gliders; the actual structural
limit should be ground-verified by static wing-load test before flight):

```
Va = sqrt(2 × n_lim × W / (ρ × S × CL_max))
   = sqrt(2 × 5 × 0.250 × 9.81 / (1.225 × 0.0296 × 0.7))
   = 31.1 m/s  → ~31 m/s
```

**Maximum dive speed** — limited by available potential energy (apogee) and terminal
velocity. In a vertical dive with quadratic drag, the fraction of Vt reached after
falling a height h is:

```
v / Vt = sqrt(1 − exp(−2 × g × h / Vt²))
```

| Apogee | h (fall distance) | v / Vt | Max dive speed |
|---|---|---|---|---|
| E16: 140 m | 100 m | 0.75 | 0.75 × 48 = **36 m/s** |
| E16: 140 m | 130 m | 0.82 | 0.82 × 48 = **39 m/s** |
| F15: 290 m | 250 m | 0.94 | 0.94 × 48 = **45 m/s** |
| F15: 290 m | 280 m | 0.95 | 0.95 × 48 = **46 m/s** |

But the dive is not perfectly vertical in practice — the glider must also navigate.
Maximum speed reached in a steep (60°) dive is ~37 m/s (E16) or ~44 m/s (F15)
at the heavier (300 g) configuration.

## Wind speed limitations

### Crosswind component

The glider's three all-moving fins (total area 0.0107 m²) can deflect ±45° at low
speed, providing yaw authority to crab into a crosswind. The practical crosswind
limit is set by landing-phase considerations (approach speed 1.3 × Vs ≈ 18 m/s),
not by fin stall:

| Parameter | Value | Notes |
|---|---|---|
| Maximum crosswind (fin authority) | ~11 m/s (40 km/h) | Fin 45°, yaw stability ratio Cnβ/Cnδ ≈ 1.3 |
| Recommended crosswind limit (first flights) | **≤5 m/s** (18 km/h) | Pilot/autopilot skill, gust margin, wingtip clearance |
| Crosswind at 25 m/s cruise (scheduled 30° deflection) | ~10 m/s (36 km/h) | Fin still has margin; enters <40 % of authority |
| Crosswind at 50 m/s (scheduled 5° deflection) | ~3 m/s (11 km/h) | Fin limited; but 50 m/s happens only in boost or a deliberate dive |

Method for the authority-based limit:

```
β_max = (Cnδ × δ_max) / Cnβ      (sideslip angle at full fin)
Cnβ ≈ 0.002/°                     (yaw stability, small glider)
Cnδ ≈ 0.0015/°                    (fin effectiveness)
δ_max = 45° at V ≤ 16 m/s

β_max = (45 × 0.0015) / 0.002 ≈ 34°
W_max = V × tan(β_max) = 17 × tan(34°) ≈ 11.5 m/s
```

### Gust response

A vertical gust adds a transient load factor. With gust-alleviation factor
Kg ≈ 0.80 for this glider:

```
Δn = Kg × ρ × V × a × S × U_g / (2 × W)
```

| Airspeed | Gust (U_g) | Δn | Total load factor (incl. 1 g) |
|---|---|---|---|---|
| 14 m/s (stall) | 5 m/s | +2.2 g | 3.2 g |
| 17 m/s (best glide) | 5 m/s | +2.7 g | 3.7 g |
| 17 m/s (best glide) | 7.5 m/s | +4.0 g | 5.0 g — **limit** |
| 25 m/s (cruise) | 5 m/s | +3.9 g | 4.9 g — near limit |
| 31 m/s (Va) | 5 m/s | +4.9 g | exceeds 5 g |

### Recommended wind limits for flight

| Condition | Limit | Rationale |
|---|---|---|
| Surface wind at launch | **<5 m/s** (<18 km/h) | Boost trajectory; rail clearance, parachute drift |
| Maximum steady wind for gliding | **<8 m/s** (<29 km/h) | Glide slope management, ground-speed control |
| Maximum gust | **<5 m/s** (<18 km/h) Gust | Structure + fin authority margin at cruise |
| Crosswind component at landing | **<5 m/s** (<18 km/h) | Wingtip clearance, flare margin, autopilot authority |

The limiting case is a gust at best-glide speed: a 7.5 m/s vertical gust reaches
the 5 g limit load. A 5 m/s gust keeps the total under 4 g with comfortable margin.
Above 8 m/s steady wind, the sink rate relative to ground increases beyond the
glider's ~3 m/s sink, making a controlled landing difficult.

### Fin deflection schedule vs wind

The speed-governed fin deflection schedule (from coludo.md) interacts with
crosswind capability:

- **≤16 m/s (full 45°):** all the yaw authority above is available — crosswind
  limit is ~11 m/s. This covers the approach and landing phase.
- **25 m/s (scheduled ~30°):** crosswind limit drops to ~10 m/s — still adequate.
- **50 m/s (scheduled 5°):** crosswind limit is ~3 m/s — but at 50 m/s the glider
  is usually boost-climbing vertically, not fighting crosswinds.
- **Below stall (<14 m/s):** the fin is aerodynamically soft (low q). These
  speeds occur only during the landing flare, where crosswind correction uses
  brief full-deflection pulses just before touchdown. Yaw authority degrades as
  v² — at 10 m/s a 45° fin generates only 35 % of the force it would at 17 m/s,
   so crosswind correction must be initiated early, before the flare.

## Design improvement notes

Recommendations arising from the STL analysis and performance estimates above.
Each item states what changes, why, and what it costs.

### 1. Wing airfoil — flat plate → cambered section

**What:** Replace the 2.4 mm flat-plate wing with a thin cambered airfoil (e.g. a
modified Clark-Y or a 4–6 % thick undercambered section). The wing is already 3 % thick
at the root — that profile could be kept but with the camber line curved.

**Why:** This is the single biggest aerodynamic gain available. Flat-plate CL_max ≈ 0.7
and L/D ≈ 5–10. A cambered section at the same Re (50 000–100 000) raises CL_max to
1.0–1.2 and L/D to 12–18. For the current 8.3 kg/m² wing loading, this means:

| Parameter | Flat plate | Cambered | Benefit |
|---|---|---|---|
| Stall speed | 14 m/s | **10–11 m/s** | Slower, safer landing |
| Best glide speed | 17 m/s | **13–14 m/s** | Stays well under 20 m/s |
| Best L/D | 5–10 | **12–18** | 2× the glide range |
| Sink rate | 1.7–3.4 m/s | **<1.5 m/s** | Softer descent |

A cambered section also delays tip stall (the current thin tip chord stalls very early),
improving roll control near the ground.

**Cost:** Lives entirely inside the existing 2.4 mm envelope if undercambered (bottom
surface curves up, top stays flat — simple to print or lay up). Weight increase is
zero (same bounding box, same shell). The wing's external planform and span stay the
same, so the folded-wing fit inside the booster is unaffected.

**Practical note:** At Re ≈ 70 000 a cambered plate outperforms a symmetric one but
is still far from a "proper" airfoil at Re > 200 000. The priority is to move the
mean camber line up ~1–1.5 mm at 30–40 % chord — a detail easily added to the STL
without redoing the wing outline.

### 2. Wing structure — flutter resistance

**What:** Add a uni-carbon spar (0.5 × 3 mm strip) along the maximum-thickness line,
or increase tip thickness from 2.4 mm to 3–4 mm.

**Why:** The wing has AR 12.1 and is 2.4 mm thick over a 598 mm span — a very flexible
structure. The flutter speed for a flat plate is approximately:

```
V_flutter ≈ k × (t/b) × sqrt(G/ρ) × sqrt(AR)
```

where t = thickness, b = span, G = shear modulus. For a 2.4 mm carbon/PLA wing
at 598 mm span, V_flutter is in the **35–50 m/s range** — right inside the dive
speed envelope. A stiffening spar raises this above Vne (47 m/s).

**Cost:** +1–2 g per wing for the strip. The tip thickness increase is also +1–2 g.
Either is negligible against the 35 g wing mass.

### 3. Wing planform — root chord and taper

**What:** Increase root chord, reduce tip chord taper ratio, or add a modest (~3–5°)
washout (twist) so the root stalls before the tip.

**Why:** The current 79 → 20 mm taper (taper ratio 0.25) with washout is acceptable,
but at AR 12.1 the tip chord of 20 mm at 2.4 mm thickness gives a very low local Re
(≈ 15 000 at best glide). That tip is essentially stalled all the time, wasting
span and reducing effective AR. A 30–35 mm tip chord (taper ratio 0.38–0.44) would
double the tip Re, improve aileron effectiveness, and only cost ~15 cm² of extra
wing area (+5 %), lowering stall speed by another 0.3 m/s.

**Cost:** +3–5 g per wing from the extra area. The slightly wider folded wing might
require the booster fairing internal clearance checked — the folded span at the tip
should stay within the 76 mm (holder) / 108 mm (locker) envelope.

**If the target is flight speed < 20 m/s,** the current wing is already adequate —
stall is at 14 m/s and best glide at 17 m/s. The cambered section (item 1) is the
only change needed to comfortably cruise at 13–14 m/s. The planform change (item 3)
is a refinement for tip-stall margin, not a requirement.

### 4. Triangular (keel-shaped) fuselage

**What:** Change the body cross-section from rectangular (46 × 50 mm) to a triangular
keel shape — wider at the bottom, narrowing toward the top.

**Why:** Three benefits:

- **Landing stability.** A flat or slightly crowned bottom is aerodynamically clean
  but tips over easily on uneven ground. A keel-shaped underside (wider base,
  ~60 mm at the bottom, ~30 mm at the top) gives a natural self-righting moment and
  protects the wings from ground impact on touchdown.

- **CG placement.** The heaviest components (battery, servos) sit in the lower,
  wider part — a keel section naturally lowers the CG, improving pendulum stability
  (equivalent to ~3–5° of dihedral effect) without adding tip weight.

- **Boost aerodynamics.** The wedge shape aligns with the airflow over the folded
  wings inside the fairing; the flat-bottomed body produces less base drag than an
  equal-volume rectangular section.

**Cost:** +3–5 g of printed structure (the wider base adds perimeter). The internal
volume is slightly larger, which helps electronics packaging. The folded wing
clearance is unaffected because the triangular section lives inside the same 46 mm
max width envelope — only the lower corner widens.

**Not recommended** as a first change — the rectangular body is light and adequate
for proving flight. Add the keel on a v2 airframe once the glide characteristics
are understood from telemetry.

### 5. Dihedral or polyhedral wing

**What:** Add 3–5° of dihedral (each wing tips up) or a polyhedral break at ~60 %
span.

**Why:** The current wing is flat (0° dihedral from the STL). A rocket-deployed
glider that separates from the booster with wings unfolding needs inherent roll
stability — especially in the first seconds after deployment when the controller
may not have a reliable attitude estimate. Dihedral provides a self-righting roll
moment in response to sideslip:

```
C_roll_dihedral ≈ −0.05 × Γ / (57.3 × AR)     (per degree of sideslip)
```

At 3° dihedral, a 5° sideslip produces ≈ −0.00022 C_roll — enough to return the
wings toward level in under 2 s at 17 m/s without the controller doing anything.

**Cost:** +0 g (purely a geometry change in the STL). The wing root must remain at
the original attachment angle so the folded-wing alignment inside the booster is
unchanged; the dihedral starts just outboard of the body.

**One caveat:** Dihedral reduces crosswind landing performance slightly (the
effective fin area in a crab is smaller). At the recommended 5 m/s crosswind limit
this is negligible.

### 6. Boost stability — fin contribution with folded wings

**What:** Verify the combined glider+booster CP/CG margin in the STL assembly, and
consider a temporary boost fin if the margin is < 1 caliber.

**Why:** During boost the wings are folded inside the fairing. The only stabilizing
surfaces are the glider's tail fins (198 mm total span) protruding from the stack.
The coludo.md original analysis flagged this as unverified. With the newer, heavier
glider (150.4 g structure), the CG may have moved, affecting stability.

The fin moment arm is the distance from the glider fins to the CG of the full stack
— roughly 290–390 mm depending on booster CG. At the measured mass distribution,
the combined CP should sit ≥ 1 caliber (40 mm) behind the combined CG for stable
boost. This can only be confirmed by balancing the physical assembly or computing
from the STL.

**Recommendation:** Before the first active-control flight, tape the glider to the
booster, find the balance point, and compare to the fin centre-of-pressure
(≈ 38–46 mm behind the body junction). If the margin is tight, add a small
expendable boost fin (thin printed PLA, 0.5 g) to the body tube.

### 7. Wing deployment — reliability margin

**What:** Add a redundant deployment mechanism — a second rubber band or a small
torsion spring at the hinge — so the wings are guaranteed to snap open even if one
band snags.

**Why:** A rocket-deployed glider has exactly one chance to deploy its wings. If a
band breaks, snags on the ejection charge wadding, or is weakened by temperature,
the glider falls ballistic. The current design relies on rubber bands anchored at
the front. Adding a torsion spring at the hinge (a 0.3 mm music-wire spring,
≈ 0.3 g) provides a mechanical backup that does not depend on the band's elastic
memory after months in the folded position.

**Cost:** ~0.3–0.5 g per hinge. Minimal impact on folded-wing stowage if the
spring is embedded in the hinge joint.

### Priority summary for a v2 iteration

| Priority | Change | Impact | Difficulty |
|---|---|---|---|
| **P0** | Cambered wing section | 2× L/D, −4 m/s stall, high confidence | Easy (STL edit) |
| **P1** | Flutter spar | Prevents wing failure in dive | Easy (adds 1–2 g) |
| **P1** | Dihedral (3–5°) | Passive roll stability at deployment | Easy (STL edit) |
| **P2** | Boost CG/CP check | Prevents tumble on ascent | Measurement, not build |
| **P2** | Tip chord increase | Better aileron authority | Medium (area +5 %) |
| **P3** | Keel fuselage | Landing stability | Medium (v2 airframe) |
| **P3** | Torsion-spring hinge | Deployment redundancy | Medium (mechanical detail) |

## Version log
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

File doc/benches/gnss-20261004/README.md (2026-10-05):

# GNSS bench 2026-10-04: why no fix on 10-03

On 10-03 no airframe fixed: **0 of 11,334 GGA rows** on TMS-7C and TMS-7D, with the receivers powered and
talking for 14.7 and 23.6 min (see
[20261003](../../../launches/20261003/README.md#gnss-is-a-bigger-antenna-needed)). The flight init switches
GSV, GSA and the antenna text off, so those logs could not tell a bad configuration from a weak signal. This
bench separates the two.

## Setup
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

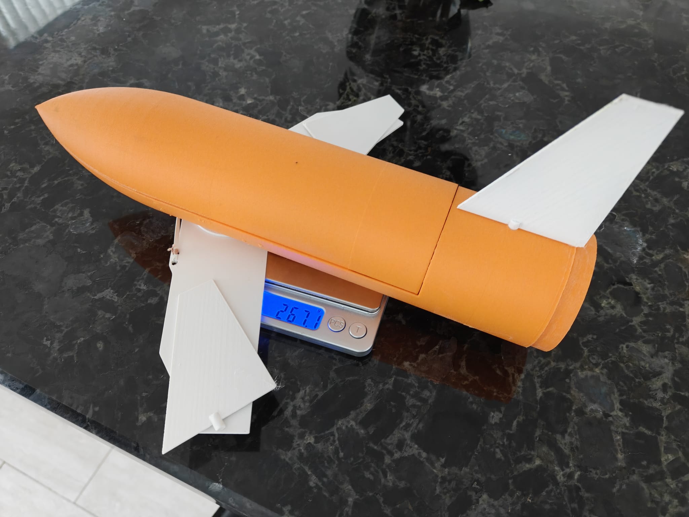
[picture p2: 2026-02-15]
doc/photos/TMS-4 with electronics weight.jpg

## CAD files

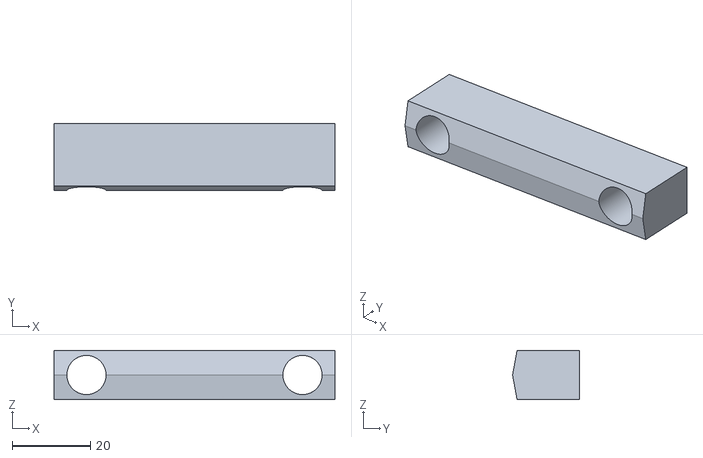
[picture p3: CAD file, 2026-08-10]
models/Catapult/Stationary Bit - Part 2.stl
71.8 x 17.1 x 12.6

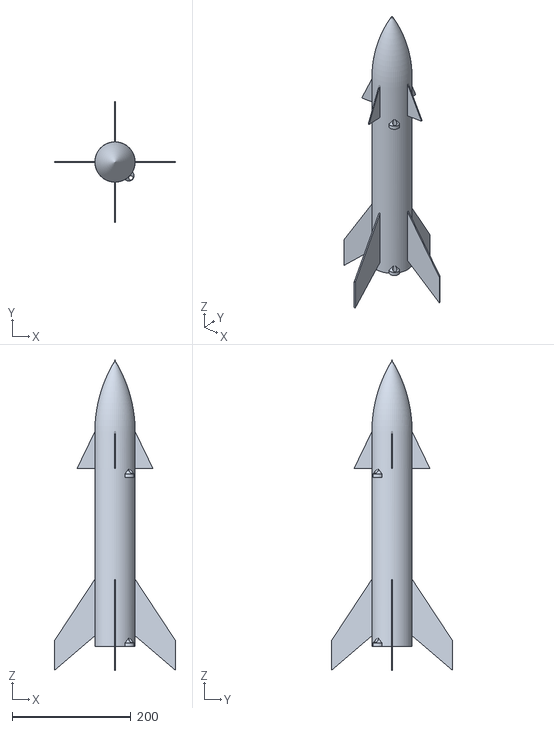
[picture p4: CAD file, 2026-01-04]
models/TMS-2.stl
204.5 x 204.5 x 522.3

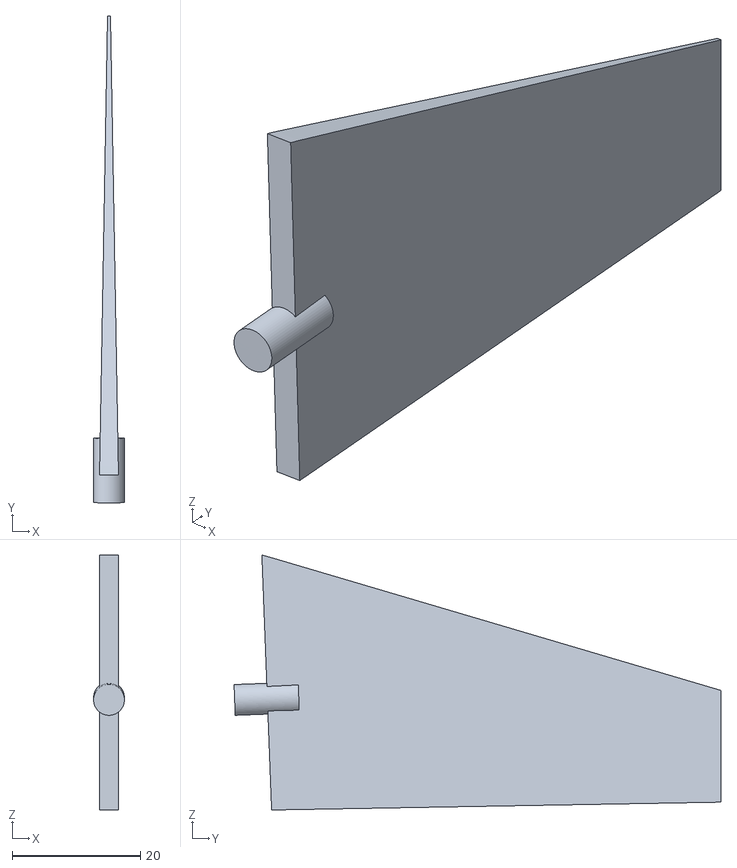
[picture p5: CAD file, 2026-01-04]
models/TMS-3/TMS-3P Flyer - Front Fin.stl
4.79 x 75.9 x 39.7

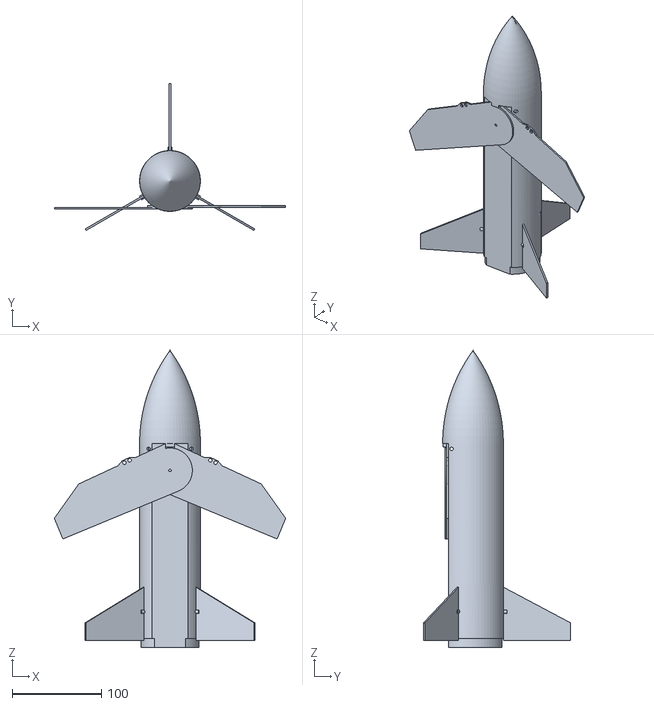
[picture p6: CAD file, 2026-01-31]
models/TMS-4/TMS-4 Glider.stl
258.7 x 164.4 x 332.0

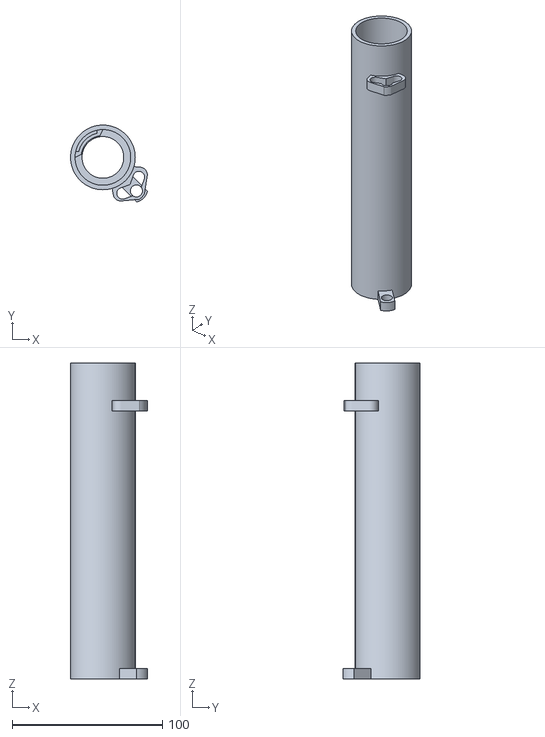
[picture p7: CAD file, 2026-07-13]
models/TMS-7/booster/Top.stl
51.1 x 51.1 x 210.0

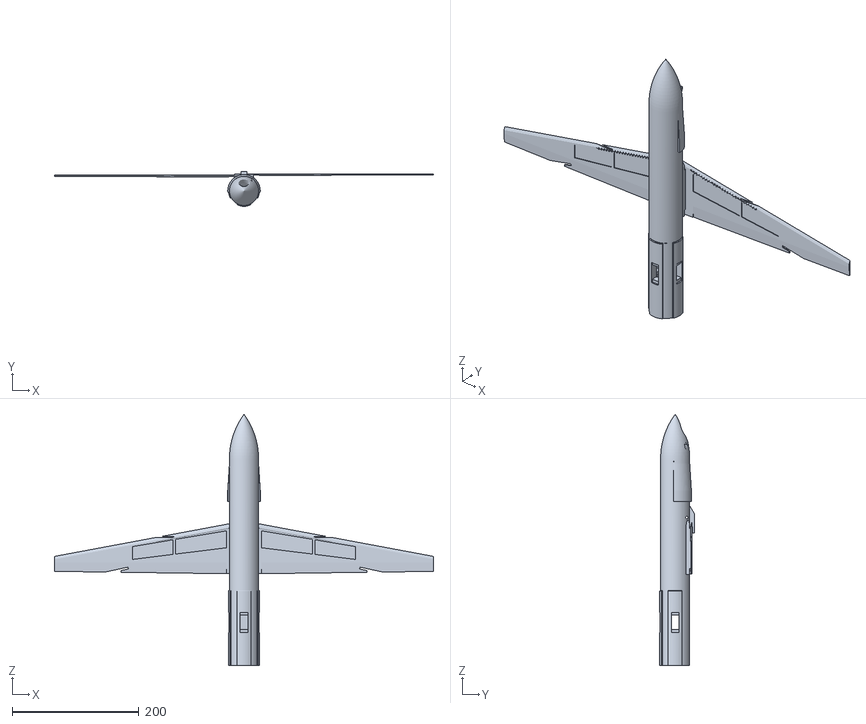
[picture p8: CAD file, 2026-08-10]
models/TMS-7/glider.stl
598.5 x 54.9 x 397.0

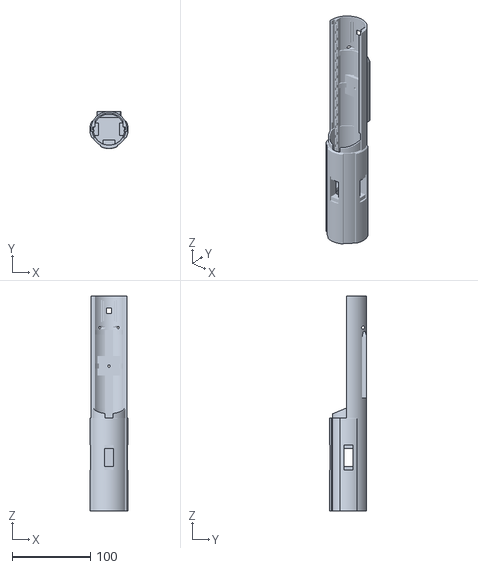
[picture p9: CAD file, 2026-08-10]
models/TMS-7/glider/Back Lower Body.stl
49.0 x 47.5 x 274.4

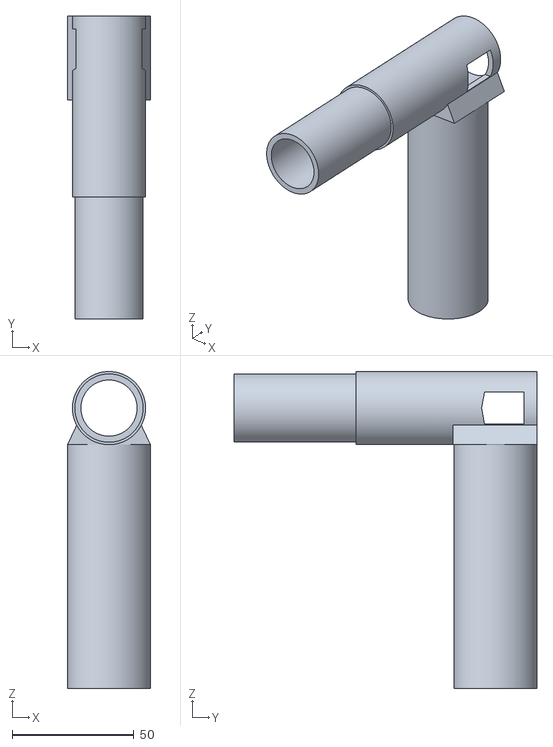
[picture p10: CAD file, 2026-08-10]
models/Catapult/Stationary Bit - Part 1.stl
34.0 x 124.2 x 130.0

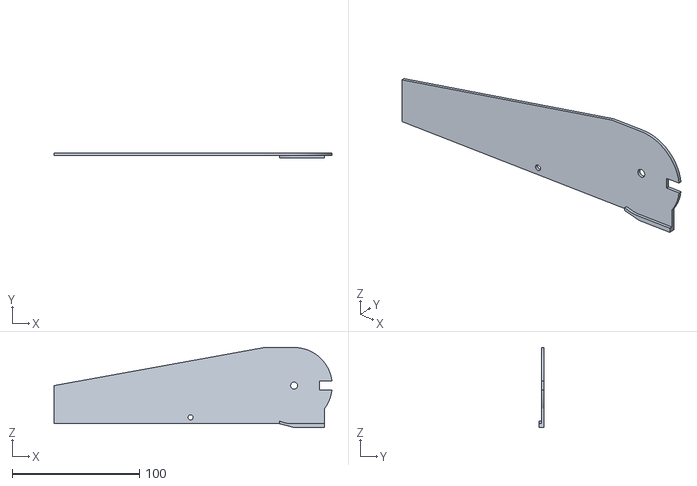
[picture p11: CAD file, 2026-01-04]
models/TMS-3/TMS-3P Flyer - Wing Right.stl
218.8 x 4.00 x 63.0

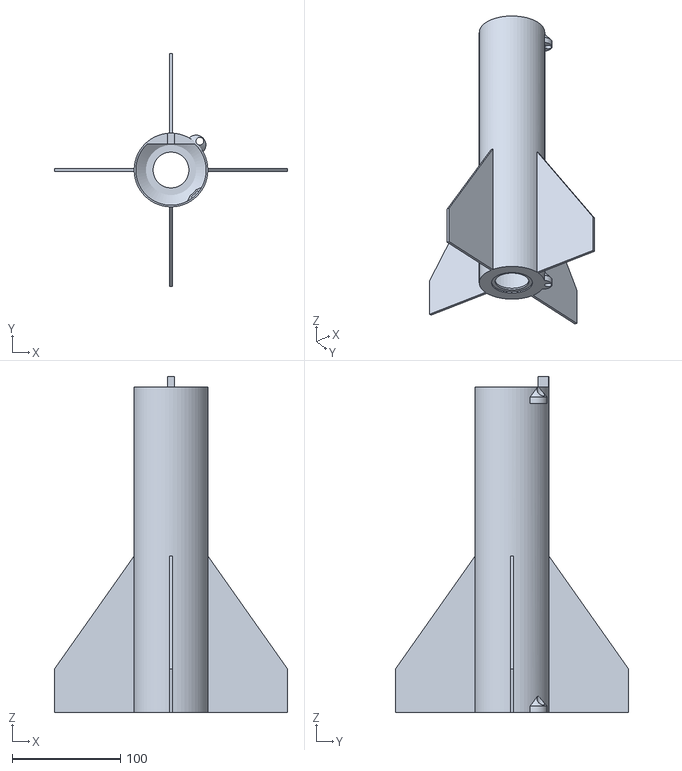
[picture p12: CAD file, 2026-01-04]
models/TMS-3P Booster.stl
215.1 x 215.1 x 309.8

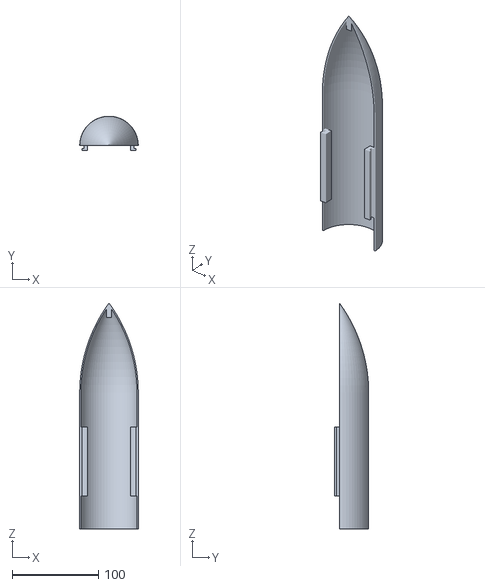
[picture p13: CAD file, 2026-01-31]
models/TMS-4/TMS-4 Glider - Body Upper.stl
68.0 x 40.0 x 262.0

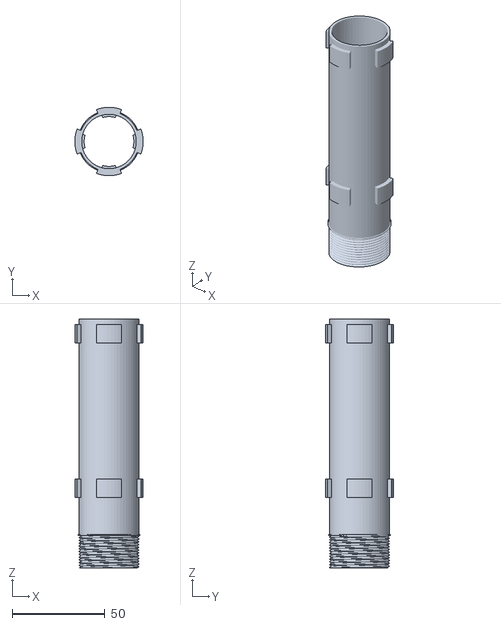
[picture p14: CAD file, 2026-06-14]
models/TMS-7/booster/TMS-7B - Holder.stl
36.9 x 36.9 x 134.5

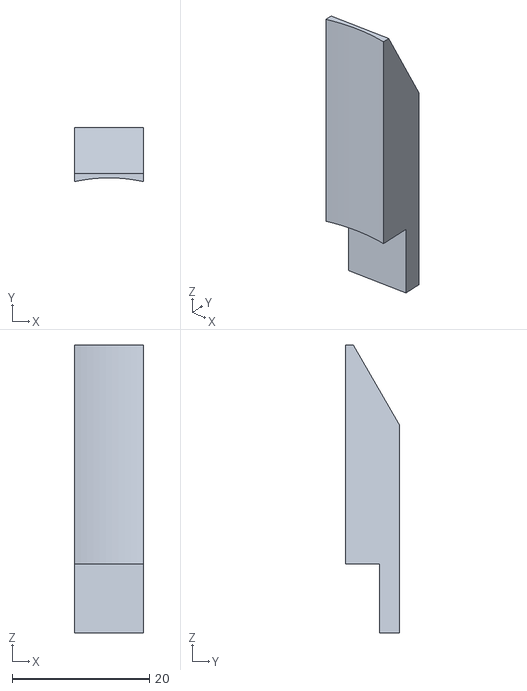
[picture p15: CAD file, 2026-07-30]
models/TMS-7/glider/Stopper.stl
10.0 x 7.92 x 42.0

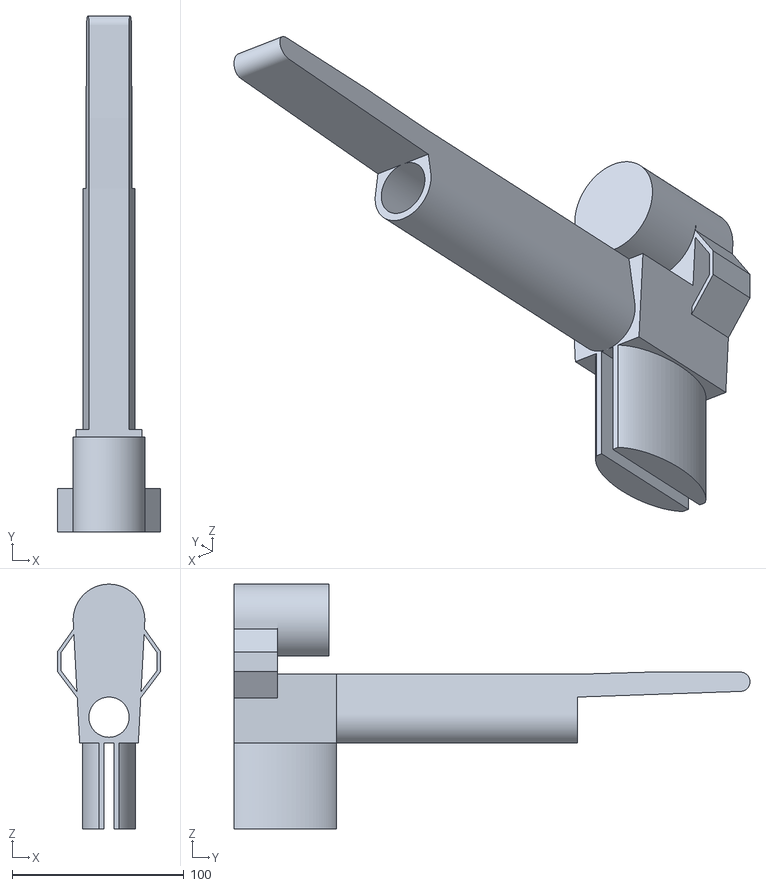
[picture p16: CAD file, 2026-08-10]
models/Catapult/Moving Bit - Part 1.stl
60.1 x 300.4 x 142.4

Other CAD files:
models/TMS-1.stl
models/TMS-3/TMS-3P Flyer - Body.stl
models/TMS-4/TMS-4 Glider - Body Lower.stl
models/TMS-7/booster/TMS-7B - Cap.stl
models/TMS-3/TMS-3P Flyer - Body Cover.stl
models/TMS-3/TMS-3P Flyer - Wing Left.stl
models/TMS-3/TMS-3PAll Together.stl
models/TMS-4/TMS-4 Booster - Booster.stl
models/TMS-4/TMS-4 Glider - Control Fin.stl
models/TMS-4/TMS-4 Glider - Wing Left.stl
models/TMS-4/TMS-4 Glider - Wing Right.stl
models/TMS-7/glider/Fin.stl
models/TMS-7/glider/Front Lower Body.stl
models/TMS-7/glider/Front Upper Body.stl
models/TMS-7/glider/Left Wing.stl
models/TMS-7/glider/Right Wing.stl

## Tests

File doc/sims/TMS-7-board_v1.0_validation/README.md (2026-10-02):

# TMS-7 — board v1.0 validation: does the rewire change anything?

**90 board flights** (3 combos × 10 scenarios × 3 runs) plus a **70 000-frame bus sweep**, flown on the
breadboard after it was rewired from the v0.1 bus layout to
[v1.0](../../hardware.md#main-board-v10--the-target-layout): four devices moved bus, `i2c:1` dropped to
100 kHz, the ADXL375 came off.

Two questions, and they want opposite answers. **The buses should get better** — that is what the rewire
was for. **The aircraft should not change at all** — the board is meant to fly the same while weighing
less, and a layout change that moved control behaviour would be cause to investigate rather than
celebrate.

Both came out that way.

## 1. The buses: 0.50 % → 0.000 %

`test/diag_bus_stability.py`, 10 000 reads per device across every bus:

| device | bus | good | corrupt | bus err |
|---|---|---|---|---|
| `baro_icp10111` | i2c:1 | **10000** | **0** | 0 |
| `airspeed_sdp810` | i2c:1 | 10000 | 0 | 0 |
| `laser_agl` | i2c:1 | 10000 | 0 | 0 |
| `imu_bno055` | i2c:0 | 10000 | 0 | 0 |
| `baro_bmp280` | i2c:0 | 10000 | 0 | 0 |
| `power_ina226` | i2c:0 | 10000 | 0 | 0 |
| `imu_lsm6dso32` | spi:1 | 10000 | 0 | 0 |

The headline is the ICP-10111. On v0.1 it corrupted **2 frames in 400 (0.50 %)** — single-bit flips in
its own CRC byte with plausible data either side, measured on the bench with the board idle. On v1.0 it
is **0 in 10 000**, where the old rate would have produced about **50 events**. A 400-frame sample could
not have said this: zero happens ~13 % of the time even at 0.50 %, which is why the frame count went up
by 25×.

**The mechanism is the clock, not isolation.** The ICP still shares a bus with the pitot and the laser —
what changed is that the bus runs at **100 kHz instead of 400 kHz**. Slower edges on a long unterminated
harness is the textbook fix for single-bit corruption in transit, and it costs nothing here because
nothing on that bus exceeds 50 Hz.

Two detectors were needed, because **five of the seven devices have no checksum**: the CRC parts are
validated by their own drivers, and everything else is read at an *identity register* whose value cannot
legitimately change, so any deviation is a bit that did not survive the wire. NAK and timeout are counted
separately from corruption throughout — a device that stops answering is a connector, one that answers
wrongly is signal integrity, and conflating them would let a loose plug read as a bus needing a slower
clock.

## 2. Detection: the board recognises itself, both ways

`layout.detect()` scans both buses before any driver binds and votes on which revision it is looking at.
Same firmware, same config, no edit:

| | i2c:0 | i2c:1 | verdict |
|---|---|---|---|
| before rewire | `0x18 0x25 0x28 0x29 0x63 0x76` | `0x40` | **v0.1, 4–0** |
| after rewire | `0x18 0x28 0x40 0x76` | `0x25 0x29 0x63` | **v1.0, 4–0** |

and then applied itself: `power_ina226 i2c:1→0 · airspeed_sdp810 i2c:0→1 · baro_icp10111 i2c:0→1 ·
laser_agl i2c:0→1 · i2c:1 400000→100000 Hz · accel_adxl375 not fitted → disabled · laser int_pin and
xshut_pin dropped`.

`diag_devices` then reported **21 up, 0 down** with every probe passing, and the board suite **58/58**.

## 3. The aircraft: unchanged, which is the point

Median miss per run, against the three-run [preflight](../TMS-7-preflight/) baseline:

| combo | preflight | v1.0 | bands |
|---|---|---|---|
| `e16_full` | 71.0 / 74.0 / 76.6 | 73.7 / 75.7 / 80.3 | overlap |
| `f15_full` | 88.0 / 90.8 / 90.9 | 70.9 / 77.8 / 83.3 | **disjoint** |
| `f15_half` | 37.1 / 39.3 / 46.3 | 42.8 / 45.1 / 49.0 | overlap |

`f15_full`'s band is disjoint and lower, and **it would be wrong to call that an improvement.** The
median moved because *variance exploded* on two scenarios, not because flights got consistently closer:

| scenario | preflight | spread | v1.0 | spread |
|---|---|---|---|---|
| `f15_full` `wind00` | 92.5 / 89.5 / 90.6 | **3.0** | 49.6 / 88.9 / 100.0 | **50.4** |
| `f15_full` `noise25` | 95.5 / 92.2 / 86.8 | 8.7 | 80.0 / 77.8 / 24.6 | **55.4** |
| `f15_half` `noise05` | 27.3 / 23.3 / 30.3 | 7.0 | 30.3 / 35.3 / 118.4 | **88.1** |

A median that falls because its inputs became less predictable is not a better aircraft. Caveat on the
claim in the other direction too: **comparing variances from three samples each is statistically weak**,
so the contrast is stark but not established.

**In-zone counts, which are the decision-relevant number:**

| combo | preflight | v1.0 |
|---|---|---|
| `e16_full` | 1/10, 1/10, 1/10 | **0/10, 0/10, 0/10** |
| `f15_full` | 0/10, 0/10, 0/10 | 0/10, 0/10, 2/10 |
| `f15_half` | **7/10, 7/10, 7/10** | 7/10, 7/10, 6/10 |

`f15_half` — the combo that matters, and the one the airframe is heading toward on mass — reproduces:
same band, essentially the same seven scenarios in zone.

**One open item, recorded rather than dismissed.** `e16_full` lost its single in-zone landing in **all
three runs**. It was `wind03`, previously the most reproducible scenario in the whole study at a **1.9 m**
spread (54.1 / 56.0 / 55.6), now 73.4 / 56.1 / 64.9. A consistent 3/3 change on the tightest scenario
deserves an explanation before the first *guided* flight. It blocks nothing today — 7C and 7D fly
fins-fixed — and one candidate mechanism is that removing the ADXL375 took `accel`'s priority-1 provider
away, so a stale LSM6DSO32 now falls to the BNO055 at a **40 ms** window instead of 20 ms, which feeds
the governor's airspeed and hence endgame timing.

## 4. Panel comparison

`tools/hitl_compare.py` across the three runs (`comparison.json`):

* **Channel dropouts: 0.** No sensor went missing in 90 flights.
* **Physically impossible values: 3**, all in rows of correct width — two gyro ranges at ~102 000 against
  a [0, 40 000] limit and one airspeed at 282 322 cm/s. Bit flips inside a field, invisible to every
  structural guard; only the physical-bounds check catches them. Same class and rate as the preflight
  study's residual.
* **Wide but expected:** `health load max` at 74–78 % and `health mem_free min` vary genuinely run to
  run, exactly as the preflight study found. Memory is not reproducible at this granularity.

## 5. Verdict

**The rewire is validated.** Bus integrity improved measurably and by a mechanism that makes sense;
detection works in both directions with no operator action; every device is up; the suite is green; and
the aircraft flies the same to within its own endgame phase variance.

**And flight-neutral is the correct result**, because the board's payoff is not accuracy but **mass**:
the deleted power and GNSS harnesses, their connectors and a shorter nose are expected at **30–50 g**,
taking the glider from 287.5 g toward 237–257 g. On this airframe
[50 g is worth 45 m of median miss and seven in-zone landings](../TMS-7-preflight/) — far more than any
control change available. The accuracy comes from the scale.

## 6. r4 — the code-polish re-fly (2026-09-16)

A 22-finding code review touched the control station, the new nose logger and **one glider file**:
`config.py`, where `config_id` stopped hashing `board.firmware_version` (load() restamps it from the
running firmware, so a byte-identical config was reporting a different id after every deploy). Nothing
in the flight path changed. r4 asks whether the aircraft noticed anyway.

**It did not**, which is the answer that was wanted:

| combo | r1–r3 medians | **r4** | r1–r3 in-zone | **r4 in-zone** |
|---|---|---|---|---|
| `e16_full` | 73.7 / 75.7 / 80.3 | **80.6** | 0/10 ×3 | **1/10** |
| `f15_full` | 70.9 / 77.8 / 83.3 | **83.2** | 0, 0, 2 /10 | **0/10** |
| `f15_half` | 42.8 / 45.1 / 49.0 | **39.6** | 7, 7, 6 /10 | **7/10** |

Every median lands inside or at the edge of its band, and `f15_half` — the combo that matters, and the
one the airframe is heading toward on mass — reproduces **7/10** exactly.

**The open item from §3 did not reproduce.** `e16_full` had lost its only in-zone landing on `wind03` in
all three previous runs; in r4 it is back (57 m, in zone). One observation against three does not settle
it, but it argues the cause is VARIABLE rather than a fixed consequence of the rewire — the more
reassuring of the two explanations, and the one that keeps this off the critical path for a fins-fixed
flight.

**Do not read `f15_half`'s 39.6 as an improvement.** §3 makes the argument against exactly that move: a
median can fall because variance grew. With one run there is no across-run spread to check, so the only
honest statement is that it is not WORSE.

**Two provenance limits, recorded rather than smoothed over:**

* One capture (`e16_full/wind06`) is stamped `build UNKNOWN` — the board did not answer the post-flight
  query. Its data is complete; only its stamp is missing.
* **The build stamp cannot see uncommitted work.** It reads the last commit, and r4 flew that commit
  plus an uncommitted working tree. The stamp exists to answer "did these runs fly the same build", and
  a dirty tree is precisely the case it cannot distinguish. Worth fixing before it misleads someone.

`config_id` also moved once, by design: taster reports `a2bd31537ad3` where it reported `e5fa26f98e9c`.
It is stable across deploys from here.

### What r4 cost, and the guards that came out of it

The first attempt produced **30 captures and zero data**, and reported `OK ... DONE` for every flight.
The recorder's filesystem was **100 % full** — 53.5 GB of camera `.mjpeg` had filled `/userdata` — so
each session got its files created and no rows written. Two combos were then lost to a CDC wedge, which
`hitl_matrix.sh` reported and gave up on.

Both failure modes now fail loudly instead:

* `hitl_collect.sh` refuses to start below 50 MB free on the recorder, and **fails when a pulled stream
  is 0 bytes** — `ls | wc -l` counts an empty file exactly like a full one, which is how thirty flights
  looked successful.
* `hitl_matrix.sh` runs `board_unwedge.py` and retries once rather than losing a ten-flight combo.
* `tools/preflight.py` gates on **1 GB** of recorder free space.

The same full-disk signature — filenames merged into data rows, stats lines cut mid-token — is what the
[postaudit regression](../TMS-7-postaudit_regression/) recorded as UART corruption "believed to be on the
receiving side and unresolved". That does not prove the historical case had this cause, but partial
writes against a full disk explain the signature better than line noise on a soldered wire, and the note
is worth revisiting rather than left standing.

## Layout

```
r1/ r2/ r3/        per-run plotly HTML + SVG, prefixed by combo
r4/                the code-polish re-fly (§5), same shape
comparison.json    the full panel comparison across the first three runs
```

## Reproducing

```bash
tools/deploy.sh
mpremote connect $PORT run src/glider/test/diag_bus_stability.py     # 10 000 frames per device
export SCENARIOS='noise05 noise10 noise25 wind00 wind03 wind06 wind09 wind12 corner_spike corner_stress'
for r in r1 r2 r3 r4; do    # r4 is the code-polish re-fly; see section 5
  GLIDER_G=285 bash tools/hitl_matrix.sh E16 /tmp/v10/$r/e16_full
  GLIDER_G=285 bash tools/hitl_matrix.sh F15 /tmp/v10/$r/f15_full
  GLIDER_G=235 bash tools/hitl_matrix.sh F15 /tmp/v10/$r/f15_half
done
```

Count the artefacts. A short run prints "matrix done" like any other.

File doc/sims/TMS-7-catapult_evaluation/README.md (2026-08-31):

# TMS-7 catapult evaluation — flying the **measured** polar

The same seven board HITL flights as [TMS-7-precatapult_evaluation](../TMS-7-precatapult_evaluation/),
re-flown with one thing changed: `sim_model.AIR_QUALITY` **2.0 → 5.5**. Nothing else moved — same
masses, same 5 % noise, same calm air, same guidance — so every delta below is attributable to the
polar alone.

5.5 is **measured**, not guessed. On 2026-08-12 a hand toss of TMS-7B (179.5 g, 2 cameras, no
avionics) glided **8.0 m from a 1.40 m release**, against a **2.70 m** ballistic reference thrown at
the same speed with an inert 173.1 g dummy of the same mass — every figure the mean of 3 attempts. The
dummy is what makes it a measurement rather than a guess: it carries the launch energy without lift,
so the glider's extra 5.3 m is bought by the wing and nothing else. Geometric and energy methods agree
to a decimal, giving **L/D 5.7** at the stated height and 5.3 if the release was really 1.5 m; **5.5 is
the midpoint** of that residual band.

The old 2.0 was an explicit placeholder — "the deliberately pessimistic worst-case floor… RE-CALIBRATES
from the first real glide telemetry". This is that re-calibration.

Treat 5.5 as a **floor**, not a best estimate: it was measured at ~5 m/s, below the airframe's trim
speed and at Re ≈ 44 000, where a thin wing is well short of its best L/D. The figure at the 7–10 m/s a
catapult or boost delivers should be better, and the sim erring pessimistic is the safe direction.

[f15_full](f15_full.html) · [f15_light](f15_light.html) · [e16_full](e16_full.html) ·
[e16_light](e16_light.html) · [calm](calm.html) · [gnss_dead](gnss_dead.html) ·
[attitude_dead](attitude_dead.html) · [**overlay**](plan_matrix.svg) · [**video**](matrix.mp4)

## Headline — accuracy got *worse*, and that is the real result

| case | q2.0 (before) | **q5.5 (now)** | in-zone | duration q2 → q5.5 |
|---|---|---|---|---|
| `e16_light` | 38 m ✅ | **42 m** | ✅ | 36.4 → 60.8 s |
| `e16_full` | 24 m ✅ | **55 m** | no | 31.4 → 49.9 s |
| `f15_full` | 82 m | **64 m** | no | 55.4 → 101.8 s |
| `calm` (0 % noise) | 52 m | **84 m** | no | 57.8 → 118.2 s |
| `f15_light` | 14 m ✅ | **84 m** | no | 62.9 → 117.8 s |
| `gnss_dead` (60 s) | 60 m | **97 m** | no | 54.8 → 99.7 s |
| `attitude_dead` (30 s) | 79 m | **149 m** | no | 55.3 → 72.0 s |

**3 in-zone → 1.** Flights roughly doubled in length, as the polar predicts, and the landings got
worse almost across the board.

That is not a regression introduced by this change. It is the change **removing a coincidence**: the
precatapult study's "first in-zone landings" were the energy budget running out at the right moment,
not the guidance holding position.

## Why — the glider now arrives with altitude to spare, and cannot spend it

Closest approach to the zone centre, and how much altitude was left at that instant (host runs, seed 1):

| case | closest approach | altitude there | flying time left | touchdown |
|---|---|---|---|---|
| `f15_215` **q2** | 3 m | **8 m** | 1 s | 13 m ✅ |
| `f15_215` **q5.5** | 2 m | **27 m** | 11 s | 101 m |
| `e16_270` **q2** | 26 m | **1 m** | 0 s | 26 m ✅ |
| `e16_270` **q5.5** | 4 m | **58 m** | 23 s | 57 m |

At the pessimistic polar the glider reached the zone with **1–8 m of altitude** — it arrived and
touched down in the same breath, so where it arrived *was* where it landed. At the measured polar it
reaches the same 2–4 m of the centre with **27–58 m in hand**, then spends the next 11–23 s flying the
holding pattern, which carries it away.

This is not a host artefact — the board flights do the same thing, and if anything more sharply:

| board flight, q5.5 | closest approach | touchdown |
|---|---|---|
| `e16_light` | **1 m** | 42 m ✅ |
| `e16_full` | **5 m** | 55 m |
| `f15_light` | **1 m** | 84 m |
| `f15_full` | **3 m** | 64 m |

**Every flight, host and board, flies within 1–5 m of the target and then lands 42–101 m away.** The
navigation is not the problem; it puts the glider over the zone every time. What is missing is any way
to *stop being* over the zone at altitude and *start being* on the ground there.

**The guidance has no mechanism to convert excess altitude into a landing at the zone.** The endgame
patterns are *positioning* patterns; none of them is an energy-dissipation pattern.

## The endgame patterns are a phase lottery, and `auto` is picking the worst one

If a pattern does not converge before touchdown, the landing point is just orbit **phase** when
altitude hits zero — so the miss is set by orbit size, and re-rolls with any change to the energy
budget. Sweeping the polar directly (F15 270 g, HPRC strip k ≈ 4.7, median of 3 seeds):

| pattern | q2.0 | q3.0 | q4.0 | q4.5 | q5.0 | q5.5 | q6.0 | q6.5 | **span** |
|---|---|---|---|---|---|---|---|---|---|
| **`o`** circle | 33 | 34 ✅ | 33 | 44 | 40 | 39 | 55 | 42 | **21 m** |
| `ov` oval | 75 | 117 | 16 ✅ | 71 | 98 | 56 | 6 ✅ | 68 ✅ | **111 m** |
| `oo` two-lobe | 64 | 53 | 59 | 68 | 17 ✅ | 82 | 64 | 15 ✅ | **67 m** |

*(✅ = in-zone on all three seeds.)* Seeds inside a column agree tightly — `ov` at q5.0 gives 98/102/98
— so the swing is **not noise**. It is the polar. `ov` moves 111 m across the range; `o` moves 21 m,
because a 30 m circle can only lose you 30 m.

The measured L/D is 5.5 with roughly ±0.2 of measurement slack, and it is a **floor** — taken below
trim speed at Re ≈ 44 000, so the real operating point is somewhere in 5–7 and will not be known
precisely until a capture with a few seconds of steady glide exists. Over that band `ov` ranges 6–98 m
and `oo` 15–82 m. **`o` is the only pattern whose accuracy can be predicted before the flight.**

`auto` currently selects on aspect alone (`guidance.Heading`: k < 2 → `o`, 2 ≤ k < 6 → `ov`, k ≥ 6 →
`oo`). The HPRC strip is k ≈ 4.7, so **`auto` flies `ov`** — the highest-variance pattern of the three.

That `OO_ASPECT = 6.0` boundary was set by [TMS-7_endgame_x3](../TMS-7_endgame_x3/) (2026-07-15), which
at quality 5 measured `ov` 27 m and `oo` 74 m and concluded "`ov` now beats `oo` at the realistic
polar". Re-measured at quality 5 on the current tree, that comes out the other way round: **`oo`
12–18 m, `ov` 98–102 m**. `guidance.py` has changed twice since (#37, #38), so these are not the same
experiment and the older number is not being called wrong — but the boundary it justifies no longer
reproduces, and the sweep above says no single-polar measurement could have justified it anyway. The
old study also reported `ov` scattering 27/219/22 m across seeds 1/2/3, where the current tree gives a
tight 98/102/98 — so what moved is not only the value.

> **Open decision, not taken here.** Pinning `endgame_pattern` to `'o'` trades the chance of a 6 m
> landing for a dependable ~40 m one. That is a design call about what the mission wants, so it is
> flagged rather than changed. The alternative — an endgame that genuinely converges (a descending
> spiral that shrinks with altitude, or an explicit dissipation phase) — is a bigger piece of work and
> the only route to landing accuracy that does not depend on knowing L/D in advance.

## Board and host now describe the same airframe

`AIR_QUALITY` used to exist twice — `sim_model.trim_sink = 7.0` on the board and
`14.0 / VF_QUALITY` defaulting to 2.0 on the host. Same physical claim, two copies, free to drift.
It is now one constant that both read. The agreement is the evidence:

| variant | host, median of 5 seeds | board HITL | host duration | board duration |
|---|---|---|---|---|
| `f15_full` (270 g) | 56 m | 64 m | 100 s | 101.8 s |
| `f15_light` (215 g) | 94 m | 84 m | 117 s | 117.8 s |
| `e16_full` (270 g) | 55 m | 55 m | 48 s | 49.9 s |
| `e16_light` (215 g) | 50 m | 42 m | 59 s | 60.8 s |

Durations match within ~2 s across a 100 s flight, and misses within ~10 m against a ±5 m seed spread.

## Also changed

- **`reachability.glide_ratio` 3.0 → 5.5.** The flight code carried its own L/D for the CC panel's
  "zone reachable y/n". It is **advisory** — `tasks/flight._flight_panel()` reads it and nothing
  steers on it — so the stale value never cost a flight, but it did tell the operator a reachable
  zone was out of range. `CONFIG_VERSION` bumped accordingly.
- **`hitl_collect.sh` wall-clock timeout 190 s → 300 s.** The board flight runs in real time and its
  own cap is 150 s; at the measured polar an `f15_light` glide lasts ~118 s where the old floor gave
  ~58 s. 190 s would have truncated the longest cases into a false `TIMEOUT`.
- **`test_sim_model.test_stall`** seeded its probe at a hardcoded `-7.0`, which *was* the old trim
  sink. Once the sink moved, the negative case passed for the wrong reason — any value above a fixed
  `-7.5` satisfies it, stalled or not. It now seeds at the trim sink itself.

## Reproduce

```bash
tools/deploy.sh
mpremote connect /dev/ttyACM0 cp tools/hitl_run.py :
for spec in "F15 f15_full 270" "E16 e16_full 270" "E16 e16_light 215" "F15 f15_light 215"; do
    set -- $spec
    bash tools/hitl_collect.sh "$1" "$2" 0.05 0.0 210.0 False captures/q55 "$3"
done
bash tools/hitl_collect.sh F15 calm          0.0  0.0 210.0 False captures/q55 270 0 0 False 0  0
bash tools/hitl_collect.sh F15 gnss_dead     0.05 0.0 210.0 False captures/q55 270 0 0 False 0  60
bash tools/hitl_collect.sh F15 attitude_dead 0.05 0.0 210.0 False captures/q55 270 0 0 False 30 0
python3 tools/flight_metrics.py captures/q55 --sort name

# the polar sweep behind the phase-lottery table (host, ~0.6 s per flight)
for q in 2.0 3.0 4.0 4.5 5.0 5.5 6.0 6.5; do for p in o ov oo; do for s in 1 2 3; do
  VF_ENDGAME=$p VF_QUALITY=$q VF_SEED=$s python3 tools/virtual_flight.py --motor F15 --noise 0.05 \
    -o /tmp/qs/${p}_q${q}_s${s}.txt --no-preflight
done; done; done
python3 tools/flight_metrics.py /tmp/qs --sort name
```

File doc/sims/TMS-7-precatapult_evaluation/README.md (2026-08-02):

# TMS-7 pre-catapult evaluation — the first in-zone landings

Seven board HITL flights on the tree that is about to fly the catapult ladder: the standard four-case
matrix (E16/F15 × full 270 g / light 215 g, 5 % noise, calm) plus a zero-noise reference and two fault
cases. Flown after `bank_limit` 30 → 45, which is the change this study exists to evaluate.

[f15_full](f15_full.html) · [f15_light](f15_light.html) · [e16_full](e16_full.html) ·
[e16_light](e16_light.html) · [calm](calm.html) · [gnss_dead](gnss_dead.html) ·
[attitude_dead](attitude_dead.html) · [**overlay**](plan_matrix.svg) · [**video**](matrix.mp4)

## Results — 3 of 7 in-zone, and every case improved

| case | before | after | in-zone | apogee | duration |
|---|---|---|---|---|---|
| `f15_light` | 85.5 m | **14 m** | ✅ | 346 m | 62.9 s |
| `e16_full` | 88.7 m | **24 m** | ✅ | 127 m | 31.4 s |
| `e16_light` | 46.8 m | **38 m** | ✅ | 161 m | 36.4 s |
| `calm` (0 % noise) | 113 m | **52 m** | no | 288 m | 57.8 s |
| `gnss_dead` (60 s) | 152 m | **60 m** | no | 288 m | 54.8 s |
| `attitude_dead` (30 s) | 138 m | **79 m** | no | 288 m | 55.3 s |
| `f15_full` | 121.7 m | **82 m** | no | 288 m | 55.4 s |

**These are the first in-zone landings this project has recorded.** Before this change every case in
every matrix read `in-zone: no`, including flights with no noise and no faults at all.

## What changed, and why it was not obvious

The loiter orbit is flown under `bank_limit`, which was **30°**. At the measured 15.6 m/s the turn floor
is `R_min = v²/(g·tan φ)` ≈ **40 m**, while `loiter_radius_m` commands **30 m** — the law was asking for
a circle physically tighter than the airframe could fly. The heading controller saturated (`roll_sp`
pinned at ±30 with `heading_err` sustained at 112–157°) and settled into a limit cycle: a ~65 m orbit
centred ~95 m off target, swinging 28 m ↔ 163 m on a ~26 s period. The period is simply how long coming
around at 30° takes. At 45° the floor drops to ~25 m and fits inside the command.

Two wrong diagnoses preceded it, both worth remembering. The first read the 121 m miss as a navigation
failure — but the zone centre is only **49.5 m from the pad** against ~860 m of available glide range,
so it was never a range problem. The second concluded bank authority was irrelevant, having checked
`land_bank_limit` (45, the *final approach*) rather than `bank_limit` (30, the *loiter*). `fin_cap` sat
at 45 the whole flight, so fin authority genuinely never clipped — the demand did.

## Fault tolerance, re-measured at the new bank

`gnss_dead` (60 s blackout, covering essentially the whole glide) now lands **60 m** out and
`attitude_dead` **79 m**, against a 52 m calm reference — so a dead receiver costs ~8 m and a dead
BNO055 ~27 m. The earlier fault matrix priced a dead GNSS at **720 m** before dead reckoning existed,
and at 152 m before this bank change.

Do not rank the two fault cases against each other from one run each: both inject at a *random* glide
moment, so single-seed scatter is large.

## Still open

- **`f15_full` at 82 m is the worst case** and the only full-mass F15 miss above 60 m. It has the most
  energy to dissipate (288 m apogee, 270 g) — the endgame likely still runs out of orbit before it runs
  out of altitude.
- **`R_min` ≈ 25 m now leaves only 5 m under `loiter_radius_m` 30 m.** The radius may be the next binding
  limit rather than the bank; check before reaching for more bank angle.
- Pattern selection (o / oo / oval) was never implicated and is unchanged.

## Chart changes in this round

Two readability fixes to `flight_report.py`, applied to every HTML here:

- **Stage markers wrap onto two lines** (`stage` / `setting`) instead of `stage -> setting`, and are
  shifted clear of their vline and right-aligned against it. They sit on a vline in an eleven-row stack,
  and the arrow form ran wide enough to overlap its neighbours whenever two transitions landed close
  together; wrapping fixed that but left the two short lines crowding the line itself, so the offset and
  alignment finish the job — both lines end at the edge nearest the marker they describe.
- **Stage markers carry the stage's DURATION** as a third line, and neighbouring markers alternate
  vertically. `setting` and `boosting` are ~0.1 s apart, so no horizontal offset can separate them —
  one has to move down. Alternating by index holds whatever the spacing, where a proximity test would
  fail on a run of three close transitions.
- **The motor BURN is shaded inside BOOSTING** (`--motor E16|F15`). BOOSTING spans burn *plus* coast to
  separation, and only the coast is under meaningful aerodynamic control — the fins have little
  authority while the motor dominates. The band makes that split visible rather than inferred, and a
  separation falling *inside* the burn is a fault the eye catches at once.
- **The 3D track is coloured BY STAGE**, one trace each, replacing the Viridis time gradient. A time
  ramp answers "when", which the hover already gives to a tenth of a second; the question actually asked
  of that chart is where it boosted, where it glided, where it turned for the landing. Stage boundaries
  are invisible on a smooth gradient. Each stage is now a legend entry, so it can be toggled off to see
  what lies underneath.

## Reproduce

```bash
tools/deploy.sh
for spec in "F15 f15_full 270" "E16 e16_full 270" "E16 e16_light 215" "F15 f15_light 215"; do
    set -- $spec
    bash tools/hitl_collect.sh "$1" "$2" 0.05 0.0 210.0 False captures/precatapult "$3"
done
# faults (last two args are attitude_drop_s and gnss_drop_s)
bash tools/hitl_collect.sh F15 calm          0.0  0.0 210.0 False captures/precatapult 270 0 0 False 0  0
bash tools/hitl_collect.sh F15 gnss_dead     0.05 0.0 210.0 False captures/precatapult 270 0 0 False 0  60
bash tools/hitl_collect.sh F15 attitude_dead 0.05 0.0 210.0 False captures/precatapult 270 0 0 False 30 0
python3 tools/flight_metrics.py captures/precatapult --sort name
# reports: pass the motor so the burn band is drawn inside BOOSTING
python3 tools/flight_report.py captures/precatapult/f15_full.txt --motor F15 -o f15_full.html
```

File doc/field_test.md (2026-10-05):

# Field ground test — no-ignition walk test (Phase 5)

The first rung of the flight-test ladder: the fully-assembled boards + firmware + CC, exercised **on the
ground with no motor and an inert booster**. Goal — confirm the whole live stack (sensors → attitude →
guidance → governor → fins → sequencer → recorder → CC link) behaves as it does in HITL, by walking the
glider around and hand-tripping the events a launch would produce (attitude, GNSS motion, a jerk for
boost-detect, a manual separation). No telemetry-launch numbers yet; this is the go/no-go before the
first powered flight.

> **Safety.** No motor is fitted; the booster is inert. **The fins move on their own once armed
> (GLIDING)** — keep fingers and clothing clear of the servos and horns. Keep the CC operator port open
> the whole time so you can disarm / force a stage. A wedged loop reboots itself (hardware watchdog);
> give it ~10 s before intervening.

## Kit
- [ ] Assembled glider (all carriers A–G plugged), inert booster, battery charged
- [ ] **CC host = the panda laptop** (this machine, WiFi AP `192.168.102.1`; the board joins as a TCP
      client) running the CC hub — board port, **operator :1235**, **web :8080**. *Fallback:* a spare PC
      runs CC in the field, then the recordings come back to the **panda** for `flight_report` / `flight_kpi` analysis
- [ ] Recorder (Luckfox) SD has free space; USB/adb cable for the post-test pull
- [ ] Open sky for GNSS; a flat patch to walk (10–30 m) with a marker for the "landing zone"
- [ ] Phone/laptop on the CC web dashboard; a second person helps (one carries, one watches CC)

---

## Phase 0 — Bench pre-checks (before leaving)
- [ ] Latest firmware deployed (`tools/deploy.sh`), correct board config; `make test` green
- [ ] Board boots to **main.py** running (boot log, not a bare REPL) and connects to CC
- [ ] **On a NEWLY SOLDERED board, run this BEFORE assembly** — it needs only USB, takes ~90 s, and
      reports the per-device failure reason rather than a bare pass/fail:
      `mpremote connect $PORT run src/glider/test/diag_devices.py`
      > Earned the hard way on 2026-08-24: a mis-routed IMU was invisible until a driver tried to talk
      > to it, by which point the board was built into the airframe and awkward to reach. Read the
      > result as a GROUP — several devices down together is usually one bus or one connector, not
      > several faults (BNO055 + BMP280 are one sen0253 module; a whole I²C bus dying at once is a
      > stuck line, and it can hard-panic the MCU rather than NAK cleanly).
- [ ] All components **verify/probe green** on CC — no sensor absent/garbage
- [ ] Fins mechanically free, correct throw; each servo horn on the right spline (re-check after)
- [ ] Confirm **no motor** and the booster is inert

## Phase 1 — Power-up & CC link (at the field)
- [ ] Power on → board joins the AP → appears on the CC dashboard, **stage = SETTING (1)**
- [ ] Every device this airframe's config enables is online — **`verify` green on CC** is the check;
      `detect` names the revision the board found. The rosters differ per revision (from the 10-03
      configs; `doc/waveshare_esp32p4_pins.md` is the generated per-revision pin/bus map):

      | | v0.1 — TMS-7C, 7D | v1.0 — TMS-7E | v1.1 — TMS-7F |
      |---|---|---|---|
      | attitude | BNO055 0x28 + BMP280 0x76 | BNO055 0x28 + BMP280 0x76 | BMI323 0x69 + BMP581 0x47 + BMM350 0x15 |
      | i2c:0 also | ICP-10111 0x63, SDP810 0x25, VL53L4CX 0x29 | INA226 0x40 | INA226 0x40 |
      | i2c:1 | INA226 0x40 (7D only; off on 7C) | ICP-10111 0x63, SDP810 0x25, VL53L4CX 0x29 | ICP-10111 0x63, SDP810 0x25, **VL53L1X** 0x29 |
      | SPI | LSM6DSO32 + ADXL375 | LSM6DSO32 (no ADXL375) | LSM6DSO32 (no ADXL375) |
      | uart | GNSS | GNSS | GNSS |
- [ ] Telemetry streaming to CC at the expected rate; `inspect` on each component looks sane
- [ ] `mem_free` stable while idle (no leak on the ground — it scans WiFi in SETTING)

## Phase 2 — Static baseline (glider level and still on the ground)
- [ ] **Attitude:** roll ≈ 0, pitch ≈ 0; rotate to a known heading (e.g. north) → **heading tracks** (magnetometer)
      > **v1.1 (TMS-7F):** heading starts at **0 at power-on, not north** — it is relative until the
      > GNSS track (> 5 m/s) teaches the magnetometer its offset, which never happens on a walk. Check
      > that heading CHANGES by the angle you turn, not what it reads.
- [ ] **Baro:** altitude/elevation steady; note the pad elevation (ground zero ≈ 0 m)
- [ ] **GNSS:** fix acquired — satellites up, HDOP low; position matches the spot
- [ ] **Airspeed:** dynamic pressure ≈ 0; do the **pad tare** (CC `update {"zero": true}` on
      `airspeed_sdp810`, glider still) → airspeed reads ~0
> 💡 **Open the walk-test HUD: `http://<cc-host>:8080/hud`.** It puts the live attitude horizon, the
> per-fin commanded angles, airspeed, the authority cap, heading-to-zone, wind, AGL and the
> stage/armed/loop-engaged state on one screen — so phases 3–5 below are *watched* rather than
> inferred. It is fully offline (no CDN) and dims itself with an age counter if the link goes stale,
> so a frozen page cannot be mistaken for a live one.

- [ ] **Fins:** disarmed → all at neutral; verify each fin's **zero/trim** via the CC fin-zero UI
      > ⚠️ **Drive servo checks through the firmware (CC / the driver), never raw PWM on one pin.** A
      > servo whose signal line is left FLOATING hunts on its own, so a bench script that drives one fin
      > and leaves the others unconfigured looks exactly like "all three fins move together" — a false
      > wiring fault that cost real time on 7/25. `sg90.setup()` gives every fin a valid PWM at bring-up,
      > which is why the fault never appears in normal operation. If you must poke a pin directly, hold
      > the other fin pins as **OUTPUT LOW** first.
- [ ] **Power:** INA226 sane at idle. It reads the **battery** (3.3-4.2 V single cell), not the 5 V
      servo rail -- ~5 V means it is sensing the wrong node. On the bench with the MCU on USB it sees
      the servos alone, so idle current looks tiny (5-14 mA); on battery it carries the MCU too
- [ ] **Separation switch:** pads nested → pin reads **HIGH = nested**

## Phase 3 — Attitude / IMU (pick it up, rotate, tilt)
- [ ] **CALIBRATE THE BNO055 — ONCE PER BOARD.** NDOF fusion does not converge without motion, and a
      glider sits still on the pad — so a perfectly healthy part can reach launch with `sys`/`mag`
      calibration at 0 and a FROZEN attitude.
      - **Rotate the airframe, don't just trace a path.** The magnetometer is fitting a sphere to the
        field vectors it has seen, so what it needs is ORIENTATION DIVERSITY: nose up, nose down,
        rolled left and right, yawed through a full circle, the 8 traced in a vertical plane as well
        as a horizontal one. A flat figure-8 with the nose on one heading shows the part almost the
        same vector throughout and leaves `mag` at 0–1 — this is the usual reason it "won't calibrate".
      - **Away from steel and magnets** — the rail, a steel bench, speakers, the motor, a laptop.
        Hard-iron distortion is the thing being measured; calibrating beside a steel table teaches it
        the table.
      - Slow and smooth, ~15–30 s, until `mag` reads **3** and the euler bytes change. Check the gyro
        column reads **> 5 °/s** while you do it — a still sample proves nothing, which is how a
        working module was once wrongly condemned.
      - Then **`calibrate imu_bno055`** over CC to save the profile to NVS — on the dashboard, the
        **send command** box: `calibrate`, params `imu_bno055`. NOT the `calibrate` action button: once
        the chip converges it drops out of the guided sweep, which then says "nothing outstanding"
        with the profile still unsaved. It is restored on every later boot, so this is a
        once-per-board bench job and NOT a pad procedure — which matters, because nobody can figure-8
        an airframe that is already on the rail.
      - `mag` dropping back to 2 afterwards is EXPECTED and no longer means anything: the register is
        the chip's confidence in its recent data, not what it has learned. The board latches the
        convergence, so `calibrated` stays true
- [ ] **CALIBRATE THE BMM350 — ONCE PER BOARD (every SEN0697 board: v1.1, and 7C on v0.1).** The SEN0697 replaces the BNO055,
      and its magnetometer is raw: nothing fuses it, so the airframe's own hard iron (servos, the motor,
      steel) sits on top of the field as a fixed vector. Measured on the bench fixture, that shifts
      heading by up to **214°** and — this is the point — by a DIFFERENT amount on every heading, so the
      track offset `attitude` learns from the GNSS cannot absorb it.
      - **POWER-CYCLE IT WHERE YOU WILL CALIBRATE, and keep it level from boot.** The calibration takes
        the min/max of every sample since BOOT, with no level gate, so a board booted on the steel
        bench, or carried tilted, bakes that into the saved centre (up to ~17° of heading). If the
        sector count will not complete, or the result looks off, a power-cycle in the clear is the
        reset; nothing else clears the evidence.
      - **A LEVEL FULL CIRCLE, not a figure-8.** Only the two horizontal axes are corrected, because
        only a level heading is used. Stand the airframe flat and turn it slowly through 360°, twice.
      - Away from steel and magnets, same as the BNO055 — you are measuring the airframe's iron, not
        the bench's.
      - The panel shows **`N of 8 sectors covered`** and counts up as you turn. It refuses a partial
        turn: a quarter circle produces a centre that is confidently wrong while looking perfectly
        round in the data, so sector coverage — not the shape — is what it checks. If the count resets
        partway, keep going; the estimate moved and it restarted against the settled one.
      - Then **`calibrate mag_bmm350`** over CC. It is saved to NVS and restored on every later boot,
        so this is a once-per-board bench job, not a pad procedure.
      - Uncalibrated is not fatal — the mag still helps through a GNSS dropout — but it stays on the
        not-ready list until done, and the heading it gives is worth much less.
- [ ] Pitch nose up / down → **pitch tracks** the right sense; roll L/R → **roll tracks**
- [ ] Yaw / spin → **heading tracks**; no glitches or freezes on quick moves (gyro rate feeds the PID D-term)
- [ ] Return to level → attitude returns to ~0/0 and the heading settles
- [ ] *(optional, redundancy — v0.1/v1.0 only)* cover/disable the BNO055 mid-test → the
      complementary-filter **backup** takes over (attitude still tracks, degraded) → re-enable. A v1.1
      board (TMS-7F) has no BNO055 and so no attitude fallback: skip this step

## Phase 4 — Fins track attitude (armed, GLIDING, hand-held)
> Reach GLIDING the realistic way (Phases 7–8) **or** force it from CC for a quick fin check. Armed = fins live.
>
> **A forced stage is a HOLD — it suppresses every stage detector until you release it.** Afterwards run
> **`stage setting`**, which returns the board to the ground *and* resumes automatic sequencing (the
> dashboard shows `STAGE HELD` while a hold is on). `stage auto` from a forced GLIDING is **not** a way
> back: the sequencer resumes from GLIDING and, on a still bench, runs straight through LANDING to DONE,
> which is terminal. `arm` and `verify` both refuse a board that is not in SETTING under automatic control.
- [ ] In GLIDING, tilt the glider → **fins deflect to counter** the attitude (stabilisation PID) — confirm the **sense is correct** (a nose-up disturbance drives the fins to push it back)
- [ ] Rotate the glider relative to the landing zone → fins **bias for the bank-to-turn heading** toward the zone
- [ ] At ~0 airspeed the **fin-authority cap is wide** (low q, safe); confirm the governor isn't clamping hard on the ground
- [ ] No servo buzz/overheat; INA226 current stays within budget during active tracking (BATTERY-side
      current, so ~1.6x the servo-rail figure for the same power -- see hardware.md)

## Phase 5 — GNSS / position + zone guidance (walk the patch)
- [ ] Set/confirm the **landing zone** in CC (e.g. `assist` hands a launch/zone position → the mission updates)
- [ ] Walk around → **position + ground track** update on CC; the guidance **heading-to-zone** and reachability recompute
- [ ] Walk toward / away / across the zone → the commanded heading (and fins, if armed) update the right way
- [ ] *(if it runs on the ground)* the wind estimate populates from the GNSS triangle — sanity only
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

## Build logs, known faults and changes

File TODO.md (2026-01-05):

== Required HW:
1. esp32-p4 with wifi
2. accelerometer+gyro
3. altimeter
4. laser altimeter (ultrasonic also possible)
5. sd card
6. battery
7. 3 servos for fins
8. button for detect stage separation
9. nice: camera, under 4k, autofocus
10. wires
all must be under 100 gramms to fit for F16 engine lift

== SW part:
1. bus for messages propagation
2. task abstraction including NVS enabling/disabling
3. console
4. stats + utilization checks
5. logging with writing to SD
6. tasks and components implementation
7. flight control task

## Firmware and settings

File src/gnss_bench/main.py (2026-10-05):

"""
Coludo project, copyright under MIT license, Alexander Moiseichuk

GNSS antenna checker -- ESP32-C6 SuperMini, MicroPython >= 1.29: an ATGM336H on UART(2) (TX -> GPIO4,
RX <- GPIO5) and a NEO-6M on UART(1) (TX -> GPIO7, RX <- GPIO6), 9600 baud.

    power-on     session N starts by itself (1, 2, ... across power cycles), no button: once a module talks,
                 it gets the FLIGHT init then the diagnostics every ~10 s (GSV, GSA, the ATGM's antenna text),
                 exactly as drivers/atgm336h.py (hz 10) and drivers/neo6mv2.py (hz 5) send them -- the drivers
                 send the diagnostics too since this bench; its first 10 lines go to its file, `336.N` / `neo6.N`
    every 10 s   a status line per module: what it is doing, fix or not
    3D fix       a module's first 3D fix saves the uptime, the situation and its last 100 lines. The flight init
                 turns GSA off, so a fix counts as 3D on a GGA with quality > 0 and >= 4 satellites (the fewest
                 a 3D solution needs), or on a GSA mode 3 if a module prints GSA
    every 30 s   moment X: `336.N.x` / `neo6.N.x` are rewritten with the situation and the last 100 lines, so
                 pulling the battery keeps what each module was doing at most 30 s before
    LED          the SuperMini's RGB LED (WS2812, GPIO8): solid green while it works, solid red once a save
                 failed

Each NMEA line is saved as `<uptime ms>;<line verbatim>`.
Events are `start;<uptime ms>`, `talking;<uptime ms>` (or `silent;` after 5 s), `tx;<uptime ms>;<command>`
(UBX as hex), `fix3d;<uptime ms>;<s since start>`, `status;<uptime ms>;<s since start>;<summary>`,
`moment;<uptime ms>;<s since start>` and `situation;<summary>`.
The summary is `rmc=;mode=;quality=;sats=;hdop=;in_view=;cn0=;antenna=;utc=;lat=;lon=;alt_m=` from the latest
RMC (A = valid fix, V = none), GSA (none/2D/3D), GGA, GSV (satellites in view and the best four C/N0, dB-Hz,
from the last burst, <= ~10 s old) and the ATGM's antenna text (OK/OPEN/SHORT). Read out with

    mpremote connect /dev/ttyACM0 cp :336.1 :336.1.x :neo6.1 :neo6.1.x <dir>/        (every N)

A power-on for the read-out starts a session too: it is the one with no status lines.
"""

import os
import struct
import time

from machine import UART, Pin
from micropython import const
from neopixel import NeoPixel

_FIRST = const(10)      # lines saved at the session start, per module
_RECENT = const(100)    # lines saved at the 3D fix and in every moment, per module
_LED = const(8)         # the SuperMini's RGB LED (WS2812) data line
_TALK_MS = const(5000)  # how long a module may stay silent after power-on before it is configured anyway
_NOISE = const(512)     # bytes without a newline: noise, not NMEA -- dropped
_SATELLITES_3D = const(4)  # the fewest satellites a 3D solution needs
_STATUS_MS = const(10000)  # a status line per module this often
_MOMENT_MS = const(30000)  # the moment files are rewritten this often
_GREEN: tuple = (0, 40, 0)   # working
_RED: tuple = (40, 0, 0)     # a save failed

"""
The flight inits, command for command with their gaps (ms): drivers/atgm336h.py at hz 10 (every
launches/20261003 config) and drivers/neo6mv2.py at hz 5 (config_default). A str is an NMEA body, bytes a
UBX class + id + payload.
"""
_ATGM_FLIGHT: tuple = (
    ('PCAS03,10,0,0,0,1,0,0,0,0,0,,,0,0', 80),
    ('PCAS02,100', 80),
    ('PMTK314,0,1,0,5,0,0,0,0,0,0,0,0,0,0,0,0,0,0,0', 80),
    ('PMTK220,100', 80),
)
_NEO_FLIGHT: tuple = (
    ('PUBX,40,RMC,0,1,0,0,0,0', 40),
    ('PUBX,40,GGA,0,5,0,0,0,0', 40),
    ('PUBX,40,GLL,0,0,0,0,0,0', 40),
    ('PUBX,40,GSA,0,0,0,0,0,0', 40),
    ('PUBX,40,GSV,0,0,0,0,0,0', 40),
    ('PUBX,40,VTG,0,0,0,0,0,0', 40),
    (b'\x06\x08' + struct.pack('<HHH', 200, 1, 1), 40),
    (b'\x06\x24' + struct.pack('<HB', 0x0001, 8) + bytes(33), 40),  # UBX-CFG-NAV5: airborne < 4 g (since 10-05)
)
"""
The diagnostics, sent after the flight init: GSV, GSA and (ATGM) the antenna text, every ~10 s -- the flight's
PCAS03 again with those dividers raised from 0 to 99 (every 99th fix at 10 Hz), and $PUBX,40 GSA/GSV every
50th fix at 5 Hz. Both only choose what is printed, so acquisition and the RMC/GGA rates stay the flight's
(measured on the bench: 10 Hz RMC + 1 Hz GGA on the ATGM, 5 Hz + 1 Hz on the NEO, GSV every ~9.9 s). Every
fix would overflow 9600 baud at 10 Hz RMC. The flight drivers adopted them as measured here: each appends
these to its init (the divider 10 x hz, the ATGM's capped at 99), so _FLIGHT + _DIAGNOSTICS is what a
board sends at hz 10 / 5, and gnss.Gnss records the result as `<name>_sky.csv`.
"""
_ATGM_DIAGNOSTICS: tuple = (('PCAS03,10,0,99,99,1,0,0,99,0,0,,,0,0', 80),)
_NEO_DIAGNOSTICS: tuple = (('PUBX,40,GSA,0,50,0,0,0,0', 40), ('PUBX,40,GSV,0,50,0,0,0,0', 40))


def _frame(command) -> bytes:
    """An NMEA body as `$body*hh\\r\\n`, or a UBX class + id + payload with its sync, length and checksum."""
    if isinstance(command, str):
        checksum = 0
        for byte in command.encode():
            checksum ^= byte
        return ('$%s*%02X\r\n' % (command, checksum)).encode()
    body = command[:2] + struct.pack('<H', len(command) - 2) + command[2:]
    first = second = 0
    for byte in body:
        first = (first + byte) & 0xFF
        second = (second + first) & 0xFF
    return b'\xb5\x62' + body + bytes((first, second))


class _Module:
    """One GNSS module: its UART, its last _RECENT lines, the latest GGA and GSA mode, and its session state."""

    def __init__(self, name: str, uart: UART, init: tuple) -> None:
        self.name = name
        self.uart = uart
        self.init = init
        self.partial = b''
        self.recent = []
        self.first = []
        self.gga = b''
        self.mode = b''
        self.rmc = b''  # the latest RMC status: A = valid fix, V = none
        self.in_view = {}  # talker -> satellites in view, from its last whole GSV group
        self.cn0 = {}  # talker -> the C/N0 values (dB-Hz) of its last whole GSV group
        self.group = []  # the C/N0 values of the GSV group being received
        self.antenna = b''
        self.path = ''
        self.first_saved = False
        self.fixed = False  # a 3D fix seen since the session start
        self.fix_saved = False
        self.active = False  # no session yet

    def start(self, session: int) -> None:
        """Begin session `session`: a fresh file name, the first lines collected anew, nothing saved yet."""
        self.path = '%s.%d' % (self.name, session)
        self.first = []
        self.first_saved = False
        self.fixed = False
        self.fix_saved = False
        self.active = True

    def poll(self, now: int) -> None:
        """Take whatever arrived: every complete line is kept, stamped `now`, and read for GGA and the GSA mode."""
        data = self.uart.read()
        if not data:
            return
        self.partial += data
        while b'\n' in self.partial:
            line, self.partial = self.partial.split(b'\n', 1)
            line = line.rstrip(b'\r')
            self.recent.append((now, line))
            if len(self.recent) > _RECENT:
                self.recent.pop(0)
            if self.active and len(self.first) < _FIRST:
                self.first.append((now, line))
            kind = line[3:7]  # '$GNGGA,...': the talker is two letters
            if kind == b'GGA,':
                self.gga = line
                fields = line.split(b',')
                if len(fields) > 7 and fields[6] not in (b'', b'0') and fields[7].isdigit():
                    self.fixed |= int(fields[7]) >= _SATELLITES_3D
            elif kind == b'GSA,':
                fields = line.split(b',')
                if len(fields) > 2:
                    self.mode = fields[2]
                    # latched: the ATGM sends a GSA per system, and a later one must not hide a 3D fix
                    self.fixed |= fields[2] == b'3'
            elif kind == b'RMC,':
                fields = line.split(b',')
                if len(fields) > 2:
                    self.rmc = fields[2]
            elif kind == b'GSV,':
                self._gsv(line)
            elif kind == b'TXT,' and b'ANTENNA' in line:
                self.antenna = line.split(b'ANTENNA ')[-1].split(b'*')[0]
        if len(self.partial) > _NOISE:
            self.partial = b''

    def _gsv(self, line: bytes) -> None:
        """One GSV sentence: collect its C/N0 values; the group's last sentence replaces that talker's view."""
        fields = line.split(b'*')[0].split(b',')
        if len(fields) < 4 or not (fields[1].isdigit() and fields[2].isdigit()):
            return
        if fields[2] == b'1':
            self.group = []
        satellites = fields[4:]
        satellites = satellites[:len(satellites) - len(satellites) % 4]  # NMEA 4.1 appends a signal id
        for index in range(3, len(satellites), 4):
            if satellites[index].isdigit():
                self.group.append(int(satellites[index]))
        if fields[2] == fields[1]:
            talker = line[1:3]
            self.in_view[talker] = int(fields[3]) if fields[3].isdigit() else 0
            self.cn0[talker] = self.group
            self.group = []

    def summary(self) -> bytes:
        """What the module is doing: RMC status, GSA mode, GGA quality/satellites/HDOP, view, C/N0, antenna, where."""
        fields = self.gga.split(b',')
        if len(fields) < 10:
            fields = [b''] * 10
        mode = {b'1': b'none', b'2': b'2D', b'3': b'3D'}.get(self.mode, b'')  # empty: no GSA yet
        best = sorted([value for values in self.cn0.values() for value in values], reverse=True)[:4]
        return (b'rmc=' + self.rmc + b';mode=' + mode + b';quality=' + fields[6] + b';sats=' + fields[7] +
                b';hdop=' + fields[8] + b';in_view=' + str(sum(self.in_view.values())).encode() +
                b';cn0=' + b','.join(str(value).encode() for value in best) + b';antenna=' + self.antenna +
                b';utc=' + fields[1] + b';lat=' + fields[2] + fields[3] + b';lon=' + fields[4] + fields[5] +
                b';alt_m=' + fields[9])


def _append(path: str, lines: list, mode: str = 'ab') -> bool:
    """
    Write `lines` (bytes, no newlines) to `path` and sync.

    Args:
        path - the file.
        lines - the lines to write.
        mode - 'ab' appends, 'wb' replaces.

    Returns:
        True once on flash; False when the write failed (printed).
    """
    try:
        with open(path, mode) as file:
            for line in lines:
                file.write(line + b'\n')
        if hasattr(os, 'sync'):
            os.sync()
        return True
    except OSError as error:
        print('gnss_bench :: %s NOT saved: %s' % (path, error))
        return False


def _stamped(lines: list) -> list:
    """(uptime ms, line) pairs as `<ms>;<line>`."""
    return [str(stamp).encode() + b';' + line for stamp, line in lines]


def _save(module: _Module, event: bytes, now: int, started: int) -> bool:
    """
    The module's 3D-fix save: the event with its uptime and seconds since the start, the situation, and the
    last _RECENT lines.

    Args:
        module - the module.
        event - b'fix3d'.
        now - ticks_ms() of the event.
        started - ticks_ms() of the session start.

    Returns:
        True once on flash.
    """
    seconds = '%.1f' % (time.ticks_diff(now, started) / 1000)
    head = event + b';' + str(now).encode() + b';' + seconds.encode()
    return _append(module.path, [head, b'situation;' + module.summary()] + _stamped(module.recent))


def _moment(module: _Module, now: int, started: int) -> bool:
    """
    Rewrite the module's moment file, `<path>.x`: the moment, the situation and the last _RECENT lines. It goes to
    a temporary file renamed over the old one, so a power cut mid-write leaves the previous moment whole.

    Args:
        module - the module.
        now - ticks_ms() of the moment.
        started - ticks_ms() of the session start.

    Returns:
        True once on flash.
    """
    seconds = '%.1f' % (time.ticks_diff(now, started) / 1000)
    head = b'moment;' + str(now).encode() + b';' + seconds.encode()
    temporary = module.path + '.tmp'
    if not _append(temporary, [head, b'situation;' + module.summary()] + _stamped(module.recent), 'wb'):
        return False
    try:
        os.rename(temporary, module.path + '.x')
        return True
    except OSError as error:
        print('gnss_bench :: %s.x NOT saved: %s' % (module.path, error))
        return False


def _configure(module: _Module) -> list:
    """Send `module` its flight init, the drivers' gaps between commands; returns the `tx` lines to save."""
    sent = []
    for command, gap_ms in module.init:
        module.uart.write(_frame(command))
        text = command.encode() if isinstance(command, str) else _frame(command).hex().encode()
        sent.append(b'tx;' + str(time.ticks_ms()).encode() + b';' + text)
        time.sleep_ms(gap_ms)
    return sent


def _sessions() -> int:
    """The highest session number on flash (0 when none), so numbering continues across power cycles."""
    highest = 0
    for name in os.listdir():
        if name.startswith('336.') and name[4:].isdigit():
            highest = max(highest, int(name[4:]))
    return highest


def _show(led: NeoPixel, colour: tuple) -> None:
    """Light the RGB LED `colour`."""
    led[0] = colour
    led.write()


def main() -> None:
    """Start session N at power-on and record until the power goes. Ctrl-C (a read-out) ends it."""
    led = NeoPixel(Pin(_LED, Pin.OUT), 1)
    _show(led, _GREEN)
    modules = [_Module('336', UART(2, 9600, rxbuf=4096), _ATGM_FLIGHT + _ATGM_DIAGNOSTICS),
               _Module('neo6', UART(1, 9600, tx=6, rx=7, rxbuf=4096), _NEO_FLIGHT + _NEO_DIAGNOSTICS)]
    session = _sessions() + 1
    started = time.ticks_ms()
    healthy = True
    for module in modules:
        module.start(session)
        healthy &= _append(module.path, [b'start;' + str(started).encode()])
    # configure a module once it talks: one powered up with the C6 may not listen yet
    while time.ticks_diff(time.ticks_ms(), started) < _TALK_MS and not all(module.recent for module in modules):
        for module in modules:
            module.poll(time.ticks_ms())
        time.sleep_ms(20)
    for module in modules:
        state = b'talking;' if module.recent else b'silent;'
        healthy &= _append(module.path, [state + str(time.ticks_ms()).encode()] + _configure(module))
    print('gnss_bench :: session %d started' % session)
    last_status = last_moment = time.ticks_ms()
    shown = None
    while True:
        now = time.ticks_ms()
        for module in modules:
            module.poll(now)
            if not module.first_saved and (len(module.first) == _FIRST or module.fixed):
                healthy &= _append(module.path, _stamped(module.first))  # fewer than 10 on an instant fix
                module.first_saved = True
            if module.fixed and not module.fix_saved:
                healthy &= _save(module, b'fix3d', now, started)
                module.fix_saved = True
                print('gnss_bench :: session %d: %s 3D fix after %.1f s' % (
                    session, module.name, time.ticks_diff(now, started) / 1000))
        if time.ticks_diff(now, last_status) >= _STATUS_MS:
            last_status = now
            seconds = ('%.1f' % (time.ticks_diff(now, started) / 1000)).encode()
            for module in modules:
                healthy &= _append(module.path, [b'status;' + str(now).encode() + b';' + seconds + b';' +
                                                 module.summary()])
        if time.ticks_diff(now, last_moment) >= _MOMENT_MS:
            last_moment = now
            for module in modules:
                healthy &= _moment(module, now, started)
        colour = _GREEN if healthy else _RED
        if colour != shown:
            _show(led, colour)
            shown = colour
        time.sleep_ms(20)


if __name__ == '__main__':
    main()

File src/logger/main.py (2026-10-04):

"""
TMS-7 nose logger: record the SEN0697 at 50 Hz from power-up to power-off, saving to flash as it goes.

Nothing is filtered: a flight can be a start and a drop inside one save window, so every sample is kept.
Records accumulate in RAM and are written as a new file every _SEGMENT records (~15 s).

LIFECYCLE. Power-on records (three long flashes, then the 0.5 s heartbeat): a missed button press must
never cost a flight, and the button is inside a closed nose cone anyway. Until a LAUNCH -- |a| over 3 g
held for 0.3 s, confirmed by a 20 m climb within 5 s, because a hard hand shake holds the 3 g too -- the
flash is a ring: when it runs short the OLDEST unprotected logs go, so a pad wait of any length costs
nothing. The launch is written to _FLIGHTS, and from one segment before it every log of that boot is a
FLIGHT: never deleted. The flight is COMPLETE after 60 s of stillness (the climb test sees a chute
descent as motion, so only the ground is still) or 10 min after the launch, whichever comes first: the
logger saves and stops -- three short flashes, then the LED solid. It also stops when the flights leave
no room for another segment, and on BOOT, the manual stop; BOOT again starts recording. TMS-7 on
2026-10-03 is why: the old ring kept recording on the ground and the walk back, and its flight was three
minutes of carrying from being overwritten.

Both sensors sample on their OWN clocks into their own FIFOs, and this loop drains them every 10 ms. That
is what makes a save lossless. Programming flash freezes the single core -- measured ~730 ms for a 72 KB
save, so ~180 ms for these 18 KB ones -- and through the freeze the BMI323 keeps queueing accel + gyro
(~3.4 s deep at 50 Hz) and the BMP581 keeps queueing pressure (32 frames, 0.64 s). The next drain collects
everything the stall would otherwise have cost. Temperature is read live: it moves too slowly to need a
FIFO, and putting it in the BMP581's halves that FIFO to 16 frames.

While NOTHING IS HAPPENING the rate drops to 1 Hz, and the first frame that moves restores 50 Hz -- so a
rocket lying hot in a closed zone for ten minutes costs ~14 KB instead of ~720 KB, and the pad wait costs
almost nothing, while the flight, the chute and every hand that picks it up stay at full rate. Stillness is
judged frame-to-frame, never against a stored resting pose: a pose would keep reading "moved" after the
airframe is set down in a new orientation, and the logger would never settle.

Timestamps come from the SENSOR's clock -- frame N is t0 + N * 20 ms, evenly spaced by construction. Each
file's header also carries the MCU clock at the save, so the host can check the two agree: a lost frame
shows as the sensor timeline falling a further 20 ms behind.

Files are bBBBBB_sSSSS.bin -- boot number (monotonic, kept in NVS) and segment -- and sort chronologically.
Header (20 bytes, <4sHHHHII): magic CLG3, record size, period ms, boot, segment, record count, MCU ms.
Record (24 bytes, <I6hii): ms, ax ay az gx gy gz, pressure, temperature -- all raw; decode.py scales them.

Nothing prints once sampling starts: with no USB host attached a console write can stall the loop.
"""

import gc
import os
import struct
import time

from machine import I2C, Pin
from micropython import const

try:
    from esp32 import NVS
except ImportError:
    NVS = None

try:
    from machine import WDT
except ImportError:                   # host: nothing to arm, and run() is board-only anyway
    WDT = None

try:
    from machine import RTC, reset
except ImportError:                   # host: no RTC memory and nothing to reset
    RTC = None
    reset = None

_SDA = const(19)
_SCL = const(20)
_LED = const(15)              # plain status LED
_BOOT = const(9)              # BOOT: a strap only at reset, an ordinary input once running

_BMI323 = const(0x69)
_BMP581 = const(0x47)

_PERIOD_MS = const(20)        # 50 Hz, both sensors
_TICK_MS = const(10)          # drain cadence: twice per frame period
_FRAME = const(14)            # one BMI323 FIFO frame over I2C: 2 dummy bytes + accel x/y/z + gyro x/y/z
_FRAME_WORDS = const(6)
_PRESSURE_DEPTH = const(32)   # BMP581 FIFO depth, pressure-only frames
_RECORD = const(24)
_SEGMENT = const(750)         # records per file: ~15 s, 18 KB
_SLACK = const(256)           # headroom: a full BMI323 FIFO drains ~170 frames in one go
_HEADER = const(20)
_RESERVE = const(32768)       # flash kept free for filesystem metadata
_NEXT = const(_HEADER + _SEGMENT * _RECORD + _RESERVE)  # the room one more full segment needs
_HEARTBEAT = const(50)        # LED toggle every 50 ticks (~0.5 s) while recording
_START_ON = const(100)        # recording started: three 1 s flashes, 0.25 s apart -- counted in ticks so
_START_OFF = const(25)        # sampling never pauses, and unmistakable against the heartbeat
_STOP_MS = const(150)         # stopped: three 150 ms flashes, then solid
_PRESS_TICKS = const(3)       # BOOT must read pressed on 3 consecutive ticks (~30 ms debounce)
_BOOST_SQUARED = const(147456)  # 3 g = 6144 LSB; compared as (LSB >> 4) squared = 384 ** 2, small ints
_BOOST_FRAMES = const(15)     # ... held for 0.3 s at 50 Hz -- which a hard hand shake CAN do (24.8 g, 16 frames
                              # on the bench), so the 3 g is only a candidate until the baro sees the climb:
_CLIMB_LSB = const(15360)     # ~240 Pa (x64 raw) = ~20 m above where the 3 g began ...
_CLIMB_FRAMES = const(250)    # ... within 5 s of it. TMS-7 climbed 20 m by 0.73 s; no hand climbs at all
_LANDED_FRAMES = const(3000)  # after a launch, 60 s still is a landing -- a chute descent never reads still
_FLIGHT_FRAMES = const(30000)  # ... and 10 min after a launch the flight is over whatever the wind does
_WATCHDOG_MS = const(8000)    # 4x the worst save ever measured (2004 ms, on a full flash)
_WATCHDOG_ARM_MS = const(4000)  # the READ-OUT WINDOW: recording starts at once, the watchdog this late
_READOUT: bytes = b'readout'  # RTC-memory flag: survives a software reset, cleared by power-off

# What counts as "something is happening". Raw LSB, so the test is integer comparisons in the hot loop.
_MOVE_LSB = const(100)        # 0.05 g of frame-to-frame accel change (2048 LSB/g); rest noise is ~5
_SPIN_LSB = const(80)         # ~5 dps on any axis (16.384 LSB/dps); rest noise measured ~1 dps
_LIFT_LSB = const(1536)       # ~24 Pa against the mark a second ago -- about 2 m, or 5 m/s under a chute
_QUIET_FRAMES = const(250)    # 5 s of stillness before decimating
_DECIMATE = const(50)         # while still, keep one frame a second

_MAGIC: bytes = b'CLG3'
_FLIGHTS: str = 'flights.txt'  # one line per launch: "boot first-protected-segment"


def _write16(bus, register: int, value: int) -> None:
    """BMI323 registers are 16-bit, written LSB first."""
    bus.writeto_mem(_BMI323, register, bytes((value & 0xFF, value >> 8)))
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

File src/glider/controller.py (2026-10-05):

"""
Coludo project, copyright under MIT license, Alexander Moiseichuk

Flight Controller -- creates and supervises the tasks described by a validated config, and tracks the
flight stage machine. See doc/specs/coludo.md ('Flight Controller', 'Tasks').

The Controller is the one task created explicitly; it creates the rest from config in a deterministic
order. Task failures are reported, not fatal (the strict/operator-authority model): a component that
fails setup is logged and skipped, and go/no-go stays with the operator via stats()/validate().
"""

import asyncio

import config as config_module
import inspector
import task

try:
    from micropython import const
except ImportError:  # CPython (tooling / off-board checks)
    from commons import const


class Stage:
    """
    The flight stages: int ids and their operator-facing names, self-contained.

    Int ids (cheap to compare/store on MicroPython) plus the `STAGES` id->name mapping (operator-facing
    names; `in Stage.STAGES` is an O(1) key check). `NAMES` is the reverse (name->id) so config that
    names stages by string resolves to an id once.

    NULL = 0 is a SENTINEL, not a flight stage: it is what an unwritten NVS checkpoint reads back, so
    a warm-start knows "no checkpoint saved". The live stages start at SETTING = 1, so any non-zero
    saved id IS a real stage to recover into. NULL is deliberately kept OUT of STAGES/NAMES -- it is
    never set_stage()-able and never has an operator name.

    Kept here, in the stage machine's own module. flight/sequencer/hitl/led import it from controller
    -- a LIGHT coupling (the module loads fast, no heavy deps pulled just for the enum). It could move
    to commons.py as the shared domain enum to drop even that import, but the gain is marginal versus
    the cross-file churn; revisit only if importing controller solely for Stage ever bites.
    """

    NULL = const(0)      # sentinel: no checkpoint saved (unwritten NVS reads 0); never a live stage
    SETTING = const(1)
    BOOSTING = const(2)
    GLIDING = const(3)
    LANDING = const(4)
    DONE = const(5)
    STAGES: dict[int, str] = {
        SETTING: 'setting',
        BOOSTING: 'boosting',
        GLIDING: 'gliding',
        LANDING: 'landing',
        DONE: 'done',
    }
    NAMES: dict[str, int] = {name: stage_id for stage_id, name in STAGES.items()}

    @staticmethod
    def active(stage: int) -> bool:
        """True during the powered boost (BOOSTING only) -- the one active-thrust stage."""
        return stage == Stage.BOOSTING

    @staticmethod
    def passive(stage: int) -> bool:
        """True while gliding unpowered, post-separation (GLIDING..LANDING) -- the boost stack is gone."""
        return Stage.GLIDING <= stage <= Stage.LANDING

    @staticmethod
    def airborne(stage: int) -> bool:
        """True while off the ground -- the union of the active boost and the passive glide."""
        return Stage.active(stage) or Stage.passive(stage)


class Controller(inspector.Inspectable):
    name: str = 'controller'
    kind: str = 'controller'

    def __init__(self, config: dict, registry: dict = None, log=None):
        self.config: dict = config
        # the CLASS registry (name -> Task class) used by create(); the INSTANCE directory is
        # self.tasks, looked up by find()/query(). Injected for tests; defaults to task.ACTIVITIES.
        self.registry: dict = registry if registry is not None else task.ACTIVITIES
        self.log = log if log is not None else (lambda msg: None)
        self.tasks: dict = {}  # name -> Task
        self.failures: dict = {}  # name -> reason, for enabled devices that did not come up (setup)
        # name -> the up device on its I2C socket feeding the same data: an unfitted ALTERNATIVE, not a fault
        self.alternatives: dict = {}
        self._runners: dict = {}  # name -> asyncio.Task
        self.stage: int = Stage.SETTING
        self.armed: bool = False  # actuation gate -- the control loop holds fins neutral until armed
        self.manual: bool = False  # operator holds the stage (ground test) -> sequencer pauses
        self.warm_started: bool = False  # a mid-air reset was recovered by the warm-start gate (degraded)
        inspector.Inspector.register(self)

    """Scope: which config entries become tasks, plus creating and finding them by name."""
    def _devices(self) -> list:
        """Sensors (data providers) + components (consumers/actuators) -- all are tasks."""
        return self.config.get('sensors', []) + self.config.get('components', [])

    def directory(self) -> list:
        """Names of enabled devices, in creation order (config order)."""
        return [device.get('name') for device in self._devices()
                if device.get('enabled', True) and device.get('name')]

    def _component(self, name: str) -> dict:
        for device in self._devices():
            if device.get('name') == name:
                return device
        return None

    def driver(self, name: str) -> str:
        """
        The driver (or activity) a configured device runs, for the operator-facing verdicts.

        "FAIL laser_agl" did not say WHICH part had failed, and on a socket declared for two parts
        that is the whole question -- so every device verdict names the implementation its config
        entry declares.

        Args:
            name - the device name.

        Returns:
            The entry's `driver`, else its `activity`; None when no configured device has that name.
        """
        comp = self._component(name)
        if comp is None:
            return None
        return comp.get('driver') or comp.get('activity')

    def _socket(self, name: str) -> tuple:
        """
        Where an I2C device answers, as (bus kind, bus id, address); None for any other device.

        Only an I2C ADDRESS identifies a socket. Two UART or PWM devices on one bus are two devices,
        never two candidates for one place. An SPI entry may carry an `addr` too, but that is its
        fallback for an I2C wiring: on SPI the chip-select is the socket, so two SPI parts that share a
        fallback address are two parts, and the dead one must stay a failure. The id compares as text
        because a JSON config may carry it either way, as bustune() already allows.

        Args:
            name - the device name.

        Returns:
            ('i2c', id as text, addr); None for an unknown device, a non-I2C one or one without `addr`.
        """
        comp = self._component(name)
        if comp is None or comp.get('bus') != 'i2c' or comp.get('addr') is None:
            return None
        return ('i2c', str(comp.get('id')), comp.get('addr'))

    def _quantities(self, name: str) -> list:
        """
        The data a device feeds the databoard: its `provides` keys, sorted.

        Args:
            name - the device name.
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

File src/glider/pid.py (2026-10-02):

"""
Coludo project, copyright under MIT license, Alexander Moiseichuk

A minimal fixed-point PID controller for the flight stabilization loop (Phase 3), sibling of mixer.py.
One instance per control axis. Anti-windup is TWO mechanisms: the integral/output clamps bound the
magnitude (and track the governor's live fin cap via set_limit()), and BACK-CALCULATION bleeds the
integral by whatever demand the saturated fin could not fly. reset() on (re)entering a control phase.

INTEGER fixed-point (fixed.fixnum in/out, integer-millisecond dt) so a step allocates NOTHING on the
heap. The flight loop runs with GC DISABLED (sequencer disables it on BOOSTING), so every heap byte
accumulates toward OOM; the old float PID boxed a fresh float on every * + / -- measured 176 B/step,
×3 axes ×100 Hz ≈ 56 KB/s of leak. This version measures 0 B/step (even at a ±180° heading swing, the
worst case for the derivative), leaving only the isolated call-site conversion
fixed.from_float(setpoint - actual) at the sensor boundary. Net saving ≈ 47 KB/s (from the
memory-refactor work).

Fixed-point contract (error/output in fixed.fixnum -- degrees × fixed.SCALE; measured alloc-free):
  error   fixnum  -- the caller scales at the boundary: fixed.from_float(setpoint - actual)
  dt      ms (int)
  gains   floats (kp/ki/kd) -- scaled by _KU=100 (0.01 gain resolution) at construction
  limits  degrees -- scaled by fixed.SCALE (to the error/output unit) at construction
  output  fixnum  -- the caller reduces: output // fixed.SCALE -> integer degrees for the mixer
The two 1000s inside step() are TIME (ms<->s), not the angle scale -- they are independent of SCALE.
Every intermediate product stays < 2**30 (the RV32 small-int ceiling; past it boxes a 16-byte mpz): at
SCALE=100 the worst term kp_k·e = 500·18000 = 9e6 and the derivative swing 36000·1000 = 3.6e7, both far
under it (SCALE=100 keeps ~3x headroom even on a scaled angle², which SCALE=1000 would overflow).
"""

from fixed import SCALE, clamp, fixnum  # fixed-point convention: error/output in SCALE-units, integer clamp
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

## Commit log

2026-01-04 models: current models added
    Models from OnShape added:
    - TMS-1, first iteration of the booster to see if it handles the forces
    - TMS-2, improved nosecone with better stability via fins
    - TMS-3P, booster and details of glider for all fins, cover, body, and wings.
    [TMS-1.stl, TMS-2.stl, TMS-3P Booster.stl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]
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2026-02-14 doc: hardware: all components received and weighted (#5)
    there are 2 most interestng configurations selected:
    A: 3 engines, required and optional components including camera, 133.8g
    B: 2 engines, the rest as in configuration A, 123.2g
    camera not add much weight but very nice to have.
    power consumption problem not yet evaluated, potential limit 5V x 0.7A
2026-02-15 doc: hardware: replace IMU to recommended one (#6)
    seems MPU6050 is a wrong device for fast tracking and ICM-45686
    better selection as per https://docs.slimevr.dev/diy/imu-comparison.html
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2026-05-03 videos: added launch footage of tms-6
    The flight happened with TMS-6C, TMS-6A crashed, center of mass should be shifted backwards by a little bit. Angle of attack on back fins should be at least -5 degrees.
    Plan for TMS-7:
    - Diameter should be reduced from 65mm to 50-55 mm.
    - Roots of the fins should be reinforced.
    - Fins angle of attack will be -5 to -10 degrees.
    - The length of the cover will be shortened to 1/3 or 1/4 of the body's length.
    - Cover must reach around half the body vertically.
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2026-06-07 specs: minor polishing for cover python issues
    Global lock (GIL) will not allow the SD card to work properly. Better to use separate power line to charge the engines.
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2026-06-14 specs: updated hardware list
    Due to the low G tolerance of the BNO055 it is replaced with the ADXL375. Also added mandatory laser range finder finder since it has been found that the barometer doesn't work at low altitudes.
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2026-06-14 docs: board-config & CC protocol specs, dev guide, benchmark, and test runner (#10)
    - specs/board-config.md: config schema, three layers, save/reboot activation model
    - specs/cc-protocol.md: CC<->board line protocol (poll model, ports 1234/1235, SSE bridge)
    - specs/coludo.md: corrected wifi(STA)/storage(no SD)/camera(on recorder); added
    "Task Data-Flow and Message Propagation"; grounded latency/GC assumptions in measurements
    - doc/skills.md: development & testing guide; doc/todo.md -> doc/plan.md with phased roadmap
    - README.md: "Where things live" repository map
    - src/glider/test/bench_asyncio.py + doc/benches: measured asyncio ~10ms sleep floor,
    O(buffer-length) bytearray slice-assign,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
2026-06-17 various improvements after phase 0 (#12)
    * docs: coding conventions (CLAUDE.md + skills.md) from findings.txt
    Codify the rules that should prevent rework: no abbreviations, _-prefixed internals (PEP8),
    type annotations on all non-locals, micropython.const (+CPython shim), docstring per entry,
    slim classes/YAGNI, async StreamWriter I/O (no blocking writes, no stop flags), error policy
    (logs drop / telemetry raises), Inspectable mixin (inspect/update/stats), positive+negative
    tests. Tooling: ruff (lint+format) + deploy.sh gate; cc_protocol shared via symlink; ssid.creds
    gitignored. New CLAUDE.md is the short always-read version pointing to skills.md.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
    [board_health.py, cc_client.py, cc_protocol.py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]
2026-06-18 implemented basic functionality and board is connected to control center (#14)
    * wishes: polish pass (Task inspectable, wifi/recorder tweaks, renames, board_pinmap)
    glider:
    - Task is now Inspectable (inspect()/stats() replace report()); the Controller registers/
    unregisters each task with the Inspector so `inspect <task>` works; Controller.report() ->
    stats(); cc_client `report` -> controller.stats().
    - _RecorderError inherits ValueError.
    - wifi: _read_password is a private method (ssid from self); ip() via try/except; set_txpower
    -> set_tx_power.
    renames/moves:
    - panda.creds.example -> SSID.creds.example (panda is our concrete homelab net).
    - src/control/itest_wifi.py -> src/control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
    [board_health.py, cc_client.py, config.py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]
2026-06-19 almost done phase 2 (#15)
    * doc/hardware.md: sync with current inventory
    Add a "Sensor & actuator inventory (on hand)" table for the parts actually available (ADXL375,
    sen0253 = BNO055+BMP280, sen0517 = ICP-10111, VL53L4CX, ATGM336H) with buses/addresses, plus the
    interchangeable options (AHT20+BMP280, MPU6050, VL53L0X/L1X). Lock the AGL laser to VL53L4CX
    (sen0648 noted as long-range fallback); clarify ADXL375 (high-G) vs BNO055 (9-DOF attitude) roles;
    note ICP-10111 = sen0517 + BMP280 backup. Replace the separation button with the chosen copper-pad
    design (HIGH=nested, LOW=separated -- polarity flipped from the old button). Expand servos with the
    candidate models (SG90 primary / MG90S / MG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
    [adxl375.py, bluetooth.py, bmp280.py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]
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2026-06-22 phase3 starting (#17)
    * recorder: random session suffix + move flight tools to tools/
    wishes 6/21 #1, #2.
    #2 (bug): a fast restart before the RTC advances produced the same
    YYYYMMDD_HHMMSS session id, so telemetry files collided on the Luckfox (a header
    spliced mid-file / clobbered data). session() now appends a `_<rand>` component
    (random.randint(100,1000)) so each boot is unique. test_recorder updated.
    #1: src/control/tools -> repo-root tools/ (alongside the other host scripts),
    synth_capture.py -> flight_synth_capture.py. The flight_telemetry session-strip
    regex now also drops the `_<rand>` component (robust to both shapes); synth +
    fixtures use the new format; the parser test imports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
    [adxl375.py, atgm336h.py, bno055.py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]
2026-06-23 phase3 improving (#18)
    * glider/servo: fold the shared slew gate into Gate (no module globals)
    Wishlist (6/22): "avoid globals globally". The process-wide slew gate was
    a module global (_gate) managed by slew_gate()/reset_gate() factory
    functions using `global`. Move the singleton onto the class itself as
    Gate._shared with Gate.slew(permits)/Gate.reset() classmethods -- same
    first-permits-win + reset-for-tests semantics, no module-level mutable
    state. Callers (sg90 driver, test_servo) updated. 35/35.
    * glider/recorder: rename _CcTee -> _TeeSink (clearer intent)
    Wishlist (6/22): the helper mirrors a stream into a bounded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
    [board.py, cc_client.py, config_default.py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]
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2026-06-28 phase4 polishing (#23)
    * doc: TMS-7 performance analysis and design recommendations
    Derived wing/fin geometry from STL meshes, computed boost performance with
    updated TMS-7 masses (E16-4/F15-4), glide performance, full speed envelope
    with methodology, wind/gust limitations, and 7-item design improvement chapter
    (cambered section, flutter spar, dihedral, keel fuselage, tip chord, boost
    stability, deployment redundancy).
    * flight_video: follow-cam, animated fins, butterfly-knife fold, 23-vertex model, smoke/exhaust/sky/HUD
    Eight visual upgrades to the HITL flight renderer:
    - Follow-cam (per-frame glider centering at 35%L/40%B of map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
    [config_hitl.py, gnss.py, icp10111.py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]
2026-06-29 phase4 prepare static burn e16 (#24)
    * tools: c3_burn_logger -- standalone ESP32-C3 logger for the TMS-7 static burn test
    A self-contained MicroPython logger that runs ON the C3 (ttyACM1), independent of the P4 flight
    computer, for the ground static burn + separation test: reads ADXL375 + LSM6DSO32 over a shared SPI
    bus + the separation switch GPIO, and writes a compact telemetry CSV to the C3's own flash.
    Thrift for the C3's small RAM / 2 MB flash: every 10 samples -> min/avg/max; IDLE writes one summary
    row per second; a launch |a| spike (>3 g) OR a separation latches FLIGHT and writes the full 100 ms
    summaries, then stops ~5 s after separation (the flight is < 5 s). So the long pre-igni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
    [adxl375.py, bluetooth.py, bmp280.py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]
2026-06-30 phase4 post fixes for hardening (#25)
    * glider/commons: SERVO_NEUTRAL_DEG -- name the fin-neutral 90
    The fin-neutral angle (90 deg) was a magic number in three places. Add
    `commons.SERVO_NEUTRAL_DEG: int = 90` (next to M_PER_DEG) and use it at the
    genuine sites: mixer.py (the `neutral_deg` fallback default), config_default
    (the default config value), and tasks/hitl.py (which *assumes* neutral = 90
    to recover fin deflections -- now explicit and greppable). A board may still
    override per surface via config `mixer.neutral_deg`.
    Left the coincidental 90s alone: sg90's `(min_deg+max_deg)//2` is the centre
    of that servo's own travel (a distinct quantity, independently set), and the
    geographic/at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
    [commons.py, config_default.py, gps.py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]
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2026-07-02 phase4 calibration and speedup (#27)
    * coludo.md: refresh the flight envelope to the measured v2 masses (sim was calibrated, table was stale)
    The "apogees read low" concern was a false alarm: the envelope table assumed old light masses (390/430 g,
    apogee 180/360 m), but the measured v2 stack is 500/517 g (booster 200/217 + 300 g glider). A hand
    integration of thrust - drag - gravity with the sim's OWN constants (Cd 0.6, A ~17 cm2) gives E16-full
    104 m / F15-full 244 m -- within a few percent of the device HITL (112 / 253 m). So sim_model needs no
    _CDA/thrust tuning; the table did. Refresh the mass basis, per-motor accels (E16 3.3 g / F15 2.84 g
    early-boost), burnout speeds, apogees, and gli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
    [bno055.py, config_default.py, config_hitl.py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]
2026-07-03 phase4 finalization refactoring (#28)
    * flight: adaptive-throttle the airspeed governor (cut the top GC-off allocator)
    _update_airspeed (|accel| sqrt + integrate + GNSS blend) is a FLOAT path and
    the biggest remaining in-flight allocator (~224 B/step, ~22 KB/s @100 Hz). It
    matters only while airspeed is fast-changing; the fin-authority cap it feeds
    varies slowly and its consumers tolerate tens of ms of lag. So:
    - FULL RATE while the speed is fast-changing -- stage < GLIDING (boost + the
    active deceleration/coast) or any speed >= airspeed_full_ms (a glide dive).
    - ADAPTIVE THROTTLE once settled below that: snap to the fast floor (min_ms,
    ~25 Hz) when the estimate moves >= airspeed_settl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
    [bmp280.py, bno055.py, commons.py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]
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2026-07-05 phase5 pre field test (#29)
    * models: TMS-7 README fin planform correction + v3 version log
    * doc: separation dynamics from the 7/03 static burn; engine holder is a consumable
    Ballistic reconstruction of the TMS-7 v3 static-burn ejection (the flight
    computer failed to power -- battery/IO-shield incompatibility -- so video +
    projectile math, not telemetry): separation velocity ~3.7 m/s (194.4 g test
    glider), ejection energy ~1.3 J, 3.5-7 g / 7-13 N over a 55-110 ms stroke,
    wings locked ~135-160 ms after exit. At full flight weight (~235-285 g) the
    same charge gives ~2.5-3.4 m/s and wings-open stretches to ~150-240 ms --
    control has no roll authority for ~0.2 s after the separation switch fi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
    [bmp280.py, config_default.py, config_hitl.py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]
2026-07-07 phase5 optimization and engine setup (#30)
    * tools: servos: moved left button pin to 4
    it is better for mounting as direct cconnection to left side of board
    * wifi: full per-network configs with per-network backoff; STA-only simplification
    Each networks[] entry is the proven panda shape replicated (user's design):
    ssid + optional enabled (default true) / policy / retry_ms / tx_power_dbm /
    password, missing keys inherited from the top-level section; bare strings
    stay ssid sugar. retry_ms is THAT network's own minimal re-attempt interval
    (per-network backoff clocks) -- a flaky hotspot is polled gently while the
    lab AP retries fast; rotation round-robins the eligible entries on a 1 s
    schedul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
    [adxl375.py, bmp280.py, bno055.py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]
2026-07-08 phase5 preparation for boards setup and HW pinning tweaks (#31)
    * board layout: INA226 -> i2c:1 (aft power bus); phase-5 carrier-split doc
    Move the INA226 off the forward i2c:0 sensor cluster onto the ESP32-P4's second
    I2C (buses.i2c.'1' = sda 31 / scl 30, hardware I2C(1)), so the forward bus stays
    short/fast and the current-sense runs a ~2 cm local bus on the aft power board.
    ALERT moves 30->29 (GPIO30 became the i2c:1 SCL). Pins 29/30/31 are real header
    pins -- the codec's own 9-13 (the machine.I2C(1) default scl9/sda8) are not
    broken out on this board, and sda8 collides with i2c:0 SCL. Scan-confirmed on
    the board: mfr 'TI', live 4987 mV / 8 mA / 25 mW through the driver; config
    validates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
    [cc_client.py, config.py, config_default.py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]
2026-07-09 phase5: closing more gaps (#32)
    * fixed/attitude: fixnum-only typing cleanup + blend_cd viper (7/08 minor changes)
    Per the 7/08 typing requests + the millis-vs-fixnum accuracy investigation:
    - fixed.atan2_cd now returns `fixnum` (centidegrees), not a bare int; args stay
    ratio-free ints. Added fixed.blend_cd -- a viper complementary-filter step
    (gyro delta + optional >>shift pull), zero float boxed. Renamed millis() ->
    to_millis() (a fixnum->milli-int telemetry converter; returns int).
    - NO `millis` TYPE. Investigated whether the CORDIC needs a x1000 scale: it is a
    ratio-free precision detail, not a semantic scale. Measured accel->roll/pitch
    error vs scale-up: x100 = 0.5 deg typica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
    [cc_client.py, config_default.py, controller.py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]
2026-07-11 phase5: close corners and cleanups (#33)
    * warmstart: extract restoration out of main + fix crumb-KeyError crash (findings §21)
    main.py was carrying the whole warm-start flow inline. Move it into warmstart.py
    (which already owns save/load/should_restore) so main is a thin bring-up, and
    harden it per findings §21:
    - §21.1 (boot-crash bug): a torn NVS crumb (valid JSON, missing key) crashed the
    boot -- `crumb['pad_altitude']` / `crumb['stamp']` were bare accesses. should_restore
    now takes now_s (not a pre-computed age_s) and reads pad_altitude/stamp via .get(),
    so a missing key REFUSES cleanly (cold boot) instead of raising mid-air. _apply_restore
    guards launch/zone the same way.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
    [adxl375.py, airspeed.py, atgm336h.py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]
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2026-07-14 phase5 final big clarification (#34)
    * models: TMS-7 v4 Derived geometry update with STL volume analysis
    - Add STL volume column to wing/fin geometry table (wings 24.2 cm³,
    fins 10.9 cm³ each)
    - Add body volume comparison table (v3→v4): glider body +11 %,
    booster −11 %, with measured weights
    - Note printed weights unchanged vs v3 despite larger volumes
    (reduced infill offset thicker walls)
    - Update performance intro to reference measured v4 masses,
    add v4 measured liftoff mass row to boost table
    - Add v4 version log entry covering booster redesign, thicker
    glider body, consolidated fin file, new parts, electronics table
    * glider: 7/13 wishes -- addr consts, read_chip_id hel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
    [adxl375.py, bluetooth.py, bmp280.py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]
2026-07-15 phase5: making proto (#35)
    * servo per-fin trim calibration + fins config section + doc sweep
    Per-fin mechanical trim (calibration):
    - sg90: per-fin `trim` (whole degrees) added at the angle->pulse boundary and
    folded into neutral, so boot / failsafe / control all land on each fin's true
    centre; live via `update {"trim": d}` (re-drives the fin) and reported in
    inspect(). Physical install is never exact, so each engine is zeroed
    individually.
    - mixer: drop the per-fin trim -- mechanical zero is now the servo's job; the
    mixer commands the common neutral only.
    - Control dashboard: a "fin zero" card -- per-fin -/+ nudges the trim live, and
    "save to board config" reads the board conf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
    [adxl375.py, airspeed.py, cc_client.py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]
2026-07-24 phase5 assembly and windspeed (#36)
    * hardware: add Converter section — servo-rail power protection
    Document the ND3A05SD 5 V/3 A isolated servo-rail converter after the Battery
    section: the ~3.5 A simultaneous peak of 3x MG90S exceeds the 3 A module, so the
    rail carries a reservoir capacitor (1000 uF low-ESR + 10 uF/100 nF ceramics at
    the servo header) as the primary protection. The module maker's series-diode
    suggestion is documented but omitted -- three small servos regenerate far less
    than one big motor and the bulk cap already absorbs the kick, avoiding the
    diode's ~0.4 V drop / ~1.4 W / fin-torque cost; a TVS clamp is the optional
    insurance. Diode guidance (Schottky >=8 A/>=20 V, +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
    [airspeed.py, bmp280.py, board.py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]
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2026-07-28 phase5: presoldering changes to make code robust (#37)
    * flight: record the control state to flight.csv (findings §27.2)
    The control loop recorded NOTHING: the airspeed estimate, the fin_cap that clipped
    every actuation, the guidance setpoints and the wind estimate lived only in the
    live `vitals()` served to CC. Post-flight you could see what the fins DID but never
    what limited them or why -- and the new pitot fusion was unverifiable in flight.
    tasks/flight: add flight.csv carrying stage, active, airspeed, fin_cap, the roll/
    pitch setpoints, heading error, the three per-axis demands and the wind estimate --
    all on ONE timestamp, so command-vs-cap is a single row. _record() runs every tick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
    [adxl375.py, airspeed.py, bmp280.py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]
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2026-07-30 models: refreshed model TMS-7 v5
    Slight update of TMS-7 model to version 5:
    - Added pitot
    - Improved Fins holders
    - Stronger stopper for wings
    - Reinforced wings
    - Better description of wiring outside main board
    [Back Lower Body.stl, Electric Pad.stl, Fin.stl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]
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2026-08-02 phase5: soldering boards (#38)
    * oom_soak: two defects that stopped it ever reaching OOM
    Running it for a production leak number showed it could not produce one.
    _ballast had ONE try around BOTH ballast loops, so the coarse loop's MemoryError
    skipped the fine loop entirely -- and a coarse chunk failing is how the coarse
    stage ENDS on a fragmented tail, it means "switch to fine", not "stop
    ballasting". Measured: it stopped at 5.03 MB free against a 600 KB target, 8x
    short, so the soak never reached OOM and timed out still gliding.
    Then it was O(n^2). gc.mem_free() was called per chunk and it walks the whole GC
    block table -- millions of blocks on a ~30 MB PSRAM heap. 99 chunks cost 80 s of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
    [adxl375.py, bmp280.py, bno055.py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]
2026-08-10 models: added reinforced TMS-7 glider
    After some tests it was determined that the glider needed further structural reinforcement, and the booster had minor sizing issues.
    [Back Lower Body.stl, glider.stl]
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2026-08-10 models: added revised version 0.2 of power board
    Revised the short circuit issue, incorrect orientation for the converter, and also changed some pads to holes.
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2026-09-05 cooking single main board v1.0 (#41)
    * docs: board now runs MicroPython 1.29.0 official; v0.2 restructuring review
    plan.md pinned the toolchain at v1.29.0-preview.414, which the board no longer
    runs. It is on 1.29.0 OFFICIAL as of today, and the full board suite is 57/57 on
    it -- no delta from the preview. The repo mpy-cross stays at preview.417
    deliberately, and that is now stated rather than left looking stale: the contract
    between compiler and runtime is the mpy FORMAT version, both sides are v6.3, and
    the passing suite is the evidence. Matching version strings would be cosmetic,
    and swapping the toolchain in the same step as the runtime would have confounded
    the comparison the update wa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
    [cc_client.py, config_default.py, layout.py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]
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2026-09-06 docs: v1.0 PCB netlist review -- the v0.1 LSM6DSO32 fault is fixed
    Reviewed models/PCBs/v1.0 against config_default and the v0.1 netlist. Traces,
    ground pour and the common 3V3 rails are deliberately preliminary at this
    revision, so the review separates CONNECTIVITY -- which is reviewable and correct
    -- from copper, which is recorded as numbers for when that work happens.
    VERIFIED. The fault that made the LSM6DSO32 read as a dead chip on both built
    boards is gone: GPIO 48 moved from L.10 (top-row SCX, the auxiliary clock) to
    L.4 (bottom-row SCL). MOSI, MISO, CS and INT1 were already correct on v0.1 and
    are unchanged, so the netlist shows ONE wiring error in v0.1 rather than the two
    this fil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
    [Drill_NPTH_Through.DRL, Drill_PTH_Through.DRL, Drill_PTH_Through_Via.DRL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]
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2026-09-06 docs: v1.0 re-export -- trace widths resolved, ground pour still outstanding
    The 2026-09-06 13:45 re-export changed ROUTING only: main_board.net is
    byte-identical, so the connectivity review stands unchanged and this is purely a
    copper update.
    The trace-width finding is resolved. Every draw used to be 0.254 mm (~0.9 A on
    1 oz) against a measured 0.79 A per MG90S and ~2.4 A for three, with the
    reservoir sized for ~4 A transients -- a 2-4x overload on the battery and servo
    paths. The board now carries three widths: 2.0 mm (30 draws, ~4 A), 0.75 mm (11,
    ~2.1 A) and 0.5 mm (159, ~1.45 A).
    The part worth checking rather than assuming is WHERE the heavy copper went, and
    it is localised: on a 142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
2026-10-02 phase5 prepare launch 1003: a lot of changes and findings during 7E and 7F cooking (#42)
    * fix: revive CC controls the single-selection refactor left wired to nothing
    Moving every action out of the board table and routing it through one `selected`
    left several controls rendered but dead, and a test suite that checked markup
    rather than bindings kept passing throughout.
    Web UI:
    - the calibration column still rendered its own `calibrate N` button, but
    bindBoardRows had stopped binding per-row controls -- it looked live and did
    nothing, leaving calibrateBoard()/sweepCalibration() orphaned. The column is
    status now; `calibrate` is a bound button in the actions bar.
    - probe and detect rea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
    [bmi323.py, bmm350.py, bmp280.py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]
2026-10-04 postmortem data collection and analysis for launch 2026/10/03 (#43)
    * logger: flight.py and flight_plots.py -- one flight on one clock, measured and drawn
    flight.py (stdlib) joins one boot's segments onto a single time axis, t = 0 at
    ignition (the first sample of the rise to a sustained 3 g), keeps 10 s of pad
    and 10 s of rest, and writes one flight.csv against the mean pad pressure. It
    prints rod exit, peak, burnout, top speed, ejection, apogee, descent bands,
    tumble, the largest shock, touchdown and rest, and with --mass/--propellant a
    thrust estimate (axial force x falling mass + drag fitted from the coast).
    Speeds and heights up to the ejection are strapdown (trapezoidal), not baro:
    th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
    [accel_adxl375.csv, airspeed_sdp810.csv, baro_bmp280.csv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]
2026-10-05 phase5 refactoring launch 1003 (#44)
    * recorder: make data logging more reliable
    commit interval reduced to 1s from 5
    disabled camera which leads to overheating during 35C outside
    * recorder: integrity wrapper, boot-id sessions, session.csv, CC clock sync
    The 2026-10-03 dumps lost ~10 % of rows on the UART, scattered rows into
    thousands of junk-named files, and named every session 2000-01-01.
    doc/specs/recorder-wire.md defines the fix; the Luckfox recorderd stays
    unchanged.
    - Board: every UART line is wrapped as [@<routing>@]{OPEN};<payload>;<CLOSE>.
    OPEN is a CRC-32 over routing+payload, CLOSE = ~OPEN ^ uptime. A viper
    routine builds it at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
    [summary.csv]
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
